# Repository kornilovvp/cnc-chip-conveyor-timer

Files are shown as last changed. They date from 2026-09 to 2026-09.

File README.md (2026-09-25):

# CNC Chip Conveyor Timer

Interval timer for a CNC chip conveyor. It presses the conveyor's **START** and
**STOP** buttons for you, in a loop, so the coolant on the swarf drains back
into the machine instead of leaving with the chips.






<!-- photo of the box on the machine: docs/photo.jpg -->

## Why

On many machines the chip conveyor is either always on or run by hand. Run
continuously it pulls the swarf out of the coolant too fast: the chips land in
the bin still wet, and a surprising amount of coolant goes with them.

Run the conveyor in short bursts instead, with a pause in between, and the
coolant drains off the belt while it stands still. Chips come out drier, the
coolant stays where it belongs.

This box does the pressing. One illuminated button, three run / pause programs,
one relay for START and one for STOP.

## How it works

```mermaid
stateDiagram-v2
    direction LR
    [*] --> SETTLE : 1 click, switched on
    SETTLE --> START_PULSE : 100 ms, both relays off
    START_PULSE --> RUN : START held 500 ms
    RUN --> STOP_PULSE : T1 elapsed
    STOP_PULSE --> PAUSE : STOP held 500 ms
    PAUSE --> START_PULSE : T2 elapsed
    [*] --> SETTLE_STOP : 2..4 clicks, mode selected
    SETTLE_STOP --> STOP_PULSE : 100 ms, both relays off
    RUN --> LAST_STOP : switched off
    PAUSE --> LAST_STOP : switched off
    LAST_STOP --> [*] : 100 ms both off, then STOP held 500 ms
```

| Mode | T1 — conveyor runs | T2 — conveyor rests |
|:---:|:---:|:---:|
| 1 | 90 s | 360 s (6 min) |
| 2 | 90 s | 720 s (12 min) |
| 3 | 90 s | 1080 s (18 min) |

The two buttons are never pressed at the same time. The rule is enforced in
the relay driver itself — pressing one lets go of the other first — and every
start of the cycle begins with 100 ms of neither button pressed.

Switching off is not a plain release of the relays. The machine holds itself
running once START has been pressed, so a timer that simply let go mid-run
would leave the conveyor going. Instead, from whatever phase the cycle is in,
the timer releases both relays for 100 ms, presses STOP once more for 500 ms,
and only then rests. A pause is no exception: STOP on a conveyor that already
stands still does nothing.

Both relays rest with their coils off, so the operator's panel buttons work as
if the timer were not there. To press a button the timer energises a relay for
500 ms: START through a normally-open contact across the START button, STOP
through a normally-closed contact in series with the machine's STOP circuit.

After **4 hours** of continuous running the timer presses STOP, switches
itself off and sounds a 15 s alarm.

## Operating it

Everything is done with the one button. A command is a series of quick clicks;
the series ends when the button stays released for 0.7 s.

| Clicks | Action |
|:---:|---|
| 1 | Switch on in the stored mode / switch off (the conveyor is stopped) |
| 2 | Mode 1 |
| 3 | Mode 2 |
| 4 | Mode 3 |

Selecting a mode stores it in flash and takes it up at once, from OFF as well
as on the run: STOP is pressed, the conveyor rests for the mode's T2, and the
cycle goes on from there with START. One click switches on with START straight
away. More than four clicks count as four. The stored mode survives a power
cycle; the device always powers up switched off.

**Sounds**

| Event | Buzzer |
|---|---|
| Power on | 2 s |
| Cycle started or restarted | 2 s |
| Switched off by the operator | 0.5 s |
| 4 h auto-off | 15 s |
| First power-on (blank settings) | SOS, once |
| Settings flash unusable | SOS at every power-on |

**Button lamp**

| State | Lamp |
|---|---|
| Off | dark |
| Running | *N* blinks, 3 s dark, *N* blinks… where *N* is the mode |
| Settings flash unusable, switched off | fast flicker |

**On-board LED (HL1)** mirrors the state for whoever has the lid open: lit
during start-up, a flash every 3 s when off, and a distinct pattern for each
phase of the cycle while running.

### When the settings flash fails

The mode is kept in a flash page that is rewritten only when the mode changes.
A power loss in the middle of a write leaves a damaged record; on the next
power-on the page is repaired automatically and the last good mode is kept. If
even that fails the timer keeps working with the mode held in RAM, and says so:
SOS instead of the power-on beep, and the button lamp flickers whenever the
device is off. It can still be switched on and off and used normally until the
board is repaired.

## Hardware

Board `PCB1_main_rev1`, 24 V supply.

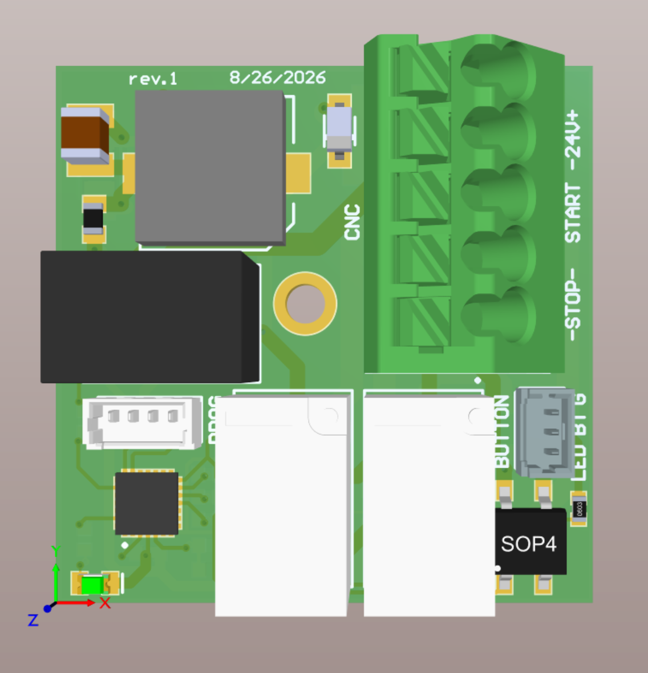
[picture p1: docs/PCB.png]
PCB1_main_rev1, 3D view of the top side


*Top side, Altium 3D view. The terminal block at the top right goes to the
machine: 24 V supply, START and STOP. The two white relays press START and
STOP. PROG is the SWD connector X2; the connector marked BUTTON goes to the
illuminated button.*

| MCU pin | Signal | Circuit |
|---|---|---|
| PB0 | `BUTTON_IN` | 10 kΩ pull-up, button to GND through 1 kΩ — active low |
| PA6 | `BUTTON_LED_ON` | 1 kΩ → CPC1014N solid-state relay → 24 V → button lamp |
| PA5 | `START_RELAY` | 1 kΩ → CPC1014N → relay K1, NO contact across the machine's START button. Energised to press |
| PA7 | `STOP_RELAY` | 1 kΩ → CPC1014N → relay K2, NC contact in series with the machine's STOP circuit. Energised to press |
| PB3 | `BUZZER` | 1 kΩ → CPC1014N → MLT-9650 active buzzer |
| PB7 | `DEBUG_LED` | 1 kΩ → HL1 |

### Rev 1 errata

- The START and STOP relay outputs were swapped on the connector in the
  original rev 1 netlist. Fixed on 2026-09-09 by renaming the nets in the
  schematic; the firmware pin labels follow (PA5 = START, PA7 = STOP). Boards
  built from the earlier netlist need the firmware labels swapped back.
- The 1 kΩ resistors feeding the CPC1014N inputs give ≈ 2.1 mA against a
  guaranteed turn-on of 2 mA. Works, but marginal; 330–470 Ω next revision.
- HL1 gets ≈ 1.2 mA and is dim.

Design sources (Altium) are in [`hardware/`](hardware/). Ready to
use: [schematic](docs/CNC_rev1_2026-09-09.PDF) and
[assembly drawing](docs/Assembly.PDF) in `docs/`.

## Firmware

STM32CubeMX generates the HAL project (`firmware/CNC_TIMER.ioc`); IAR
Embedded Workbench builds it (`firmware/EWARM/Project.eww`). Everything the device does lives in
the `Core/` sources; the CubeMX-generated files are only touched inside their
`USER CODE` sections.

A prebuilt image is kept in [`firmware/hex/`](firmware/hex/) — flash it over
SWD with STM32CubeProgrammer at `0x08000000` if you only want to run the board.

### Building

1. IAR Embedded Workbench for Arm 9.1 (any 9.x should do). STM32CubeMX is only
   needed if you change `CNC_TIMER.ioc`; the generated files are committed.
2. Open `firmware/EWARM/Project.eww`, build. The image lands in
   `firmware/EWARM/CNC_TIMER/Exe/CNC_TIMER.hex` (the output converter is on).
3. Flash over SWD. X2 has no NRST line, so the debugger cannot reset the
   board — power-cycle it instead.
4. Compiler optimisation is **switched off** (Level: None) in the project
   file, and the shipped `.hex` is built that way. Regenerating the project
   in CubeMX puts back its default, High / Size — set it to None again under
   Project → Options → C/C++ Compiler → Optimizations.

| Module | Job |
|---|---|
| `button.c` | Debounce, click-series detector, deaf/listening gate |
| `relay.c` | The two relays, mutual exclusion, polarity |
| `cycle.c` | START / RUN / STOP / PAUSE state machine |
| `settings.c` | Mode in the last flash page, append-only log, repair, fault flag |
| `indicator.c` | Button lamp: blink bursts, flicker |
| `buzzer.c` | Beeps and the Morse SOS |
| `debug_led.c` | HL1 patterns |
| `app.c` | Power-on signature, OFF / RUN, click dispatch, 4 h clock, sounds |
| `main.c` | Wiring only |

The main loop never blocks. `Button_Tick()` runs from SysTick every 1 ms; every
other module is polled from the loop and works from `HAL_GetTick()`.

The settings page is the last 2 KB of flash (`0x0801F800`); the linker script
ends ROM one page early so no code can land there. Firmware from before
2026-09-24 had five programs; its stored mode is not carried over — the first
power-on after the update repairs the page and starts at mode 1.

Every module exposes a `volatile` `g_*` structure for the IAR Live Watch
window — counters, live values, measured timings — so the board can be read
without a printf.

## Repository layout

```
firmware/   STM32CubeMX project (CNC_TIMER.ioc), HAL drivers, IAR workspace in EWARM/
hardware/   Altium Designer sources of PCB1_main_rev1 (schematic, PCB, Draftsman assembly drawing)
docs/       schematic and assembly PDFs, PCB render, operator's guide (A4), button labels (150 x 20 and 50 x 150 mm)
```

For the operator: [one-page guide](docs/operator-guide-A4.pdf) and a
label to stick next to the button, [150 × 20 mm strip](docs/button-label-150x20.pdf)
or [50 × 150 mm vertical](docs/button-label-50x150.pdf) — all generated from the
`.html` files beside them; print at 100 %.

## Status

Testing. The firmware builds and runs on the rev 1 board: button, relay
cycle, mode selection and storage, indication and sounds all work. Long-run
behaviour (the 4 h auto-off, flash wear, the fault paths) is still being
exercised before the first release.

## License

MIT — see [`LICENSE`](LICENSE).

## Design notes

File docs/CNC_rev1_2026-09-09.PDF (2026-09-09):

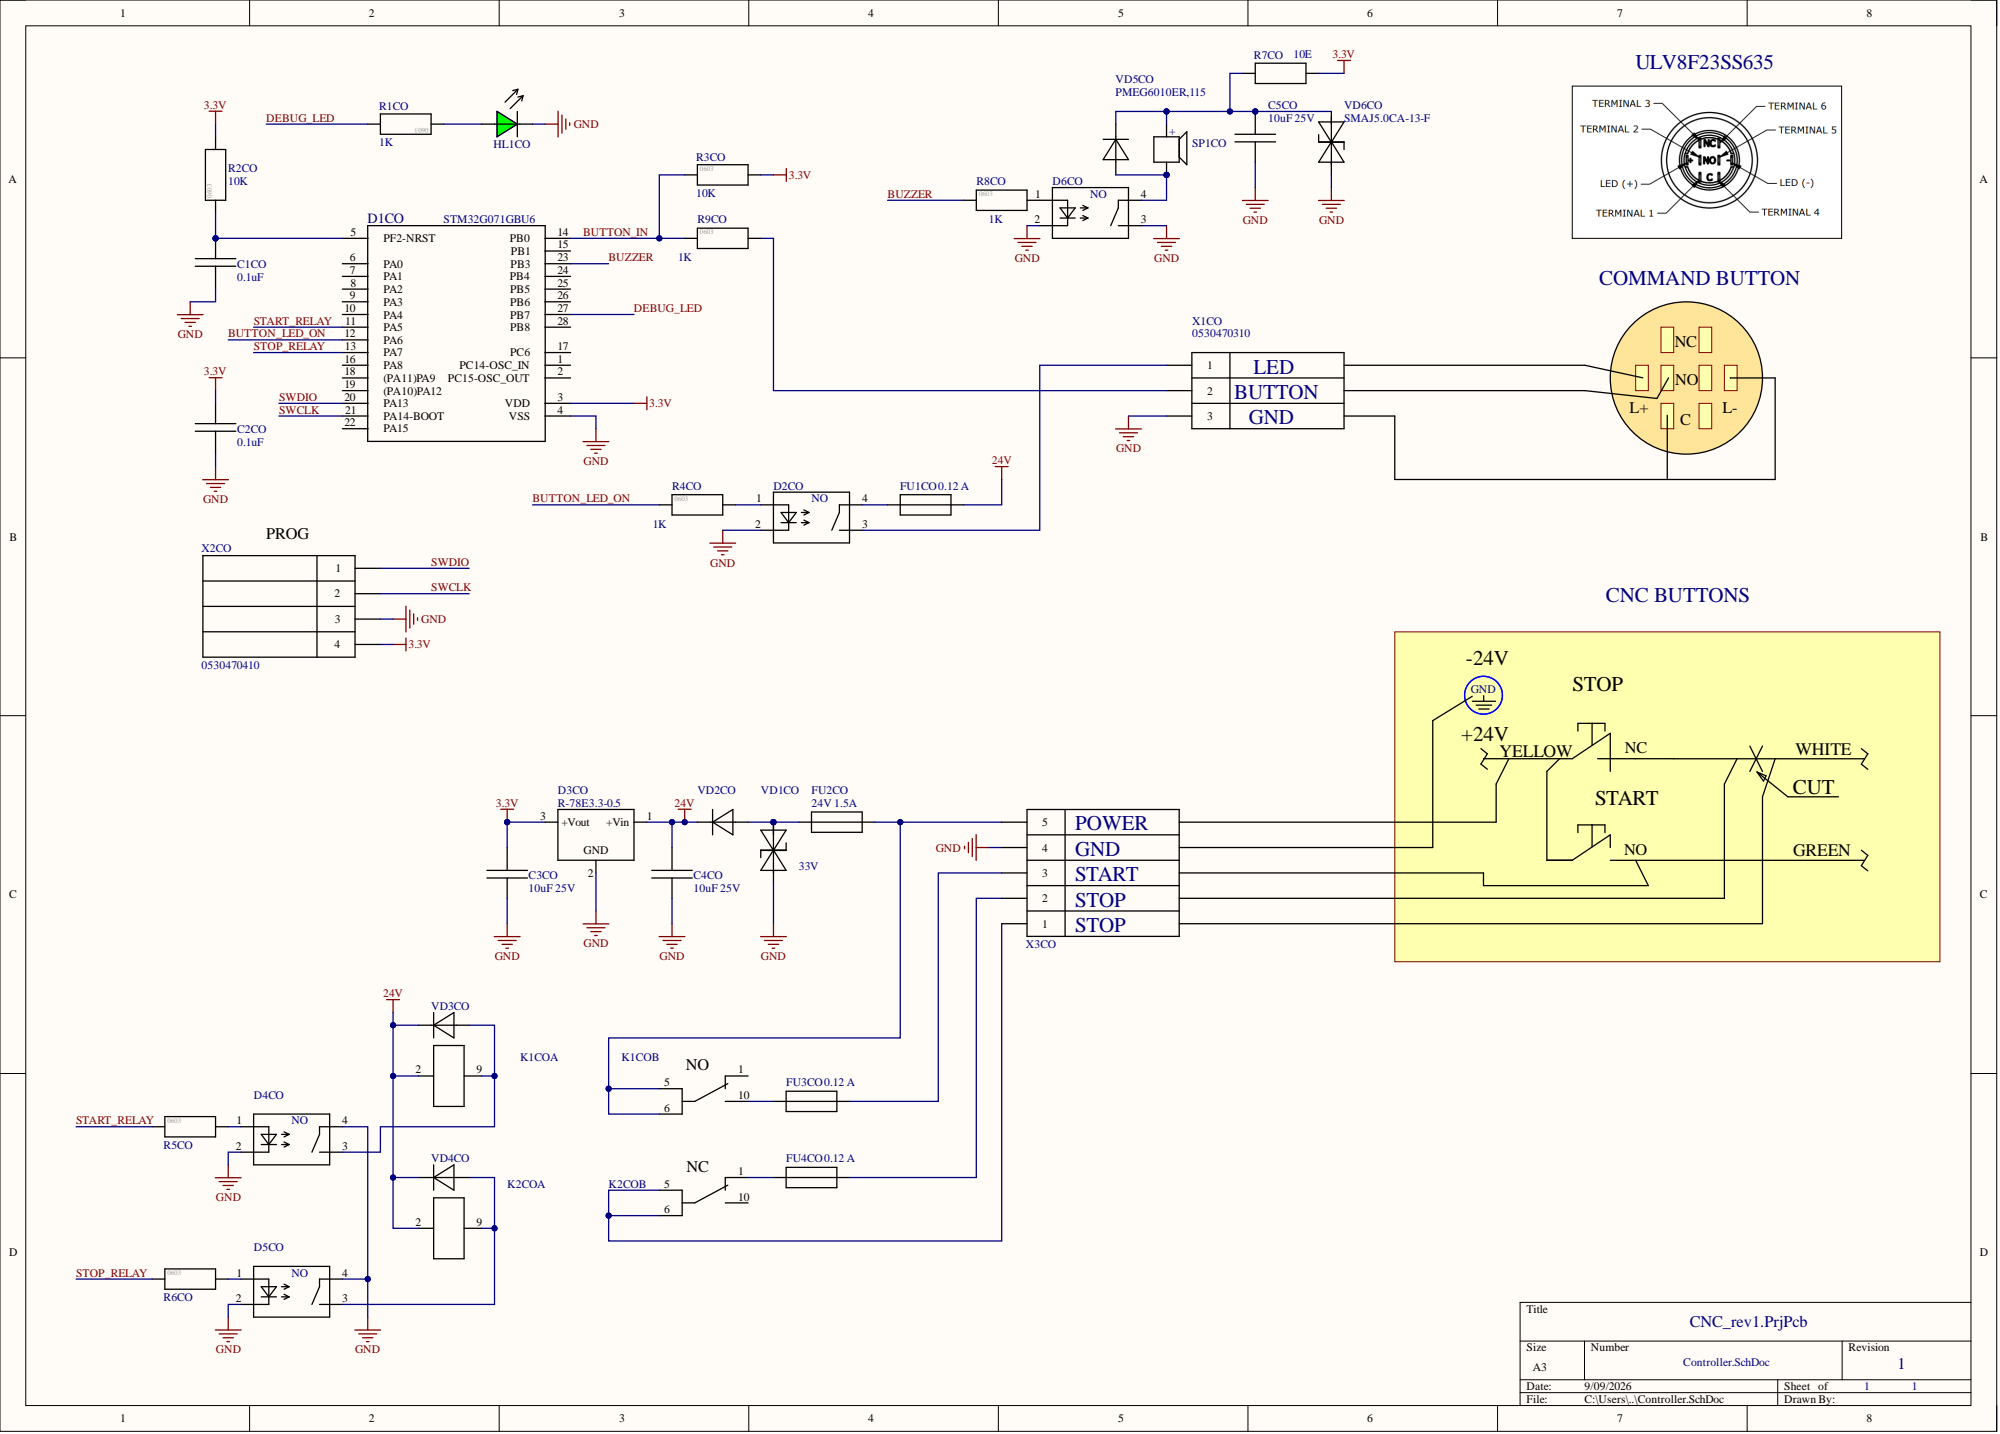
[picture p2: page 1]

4 | GND
3 | START
2 | STOP
1 | STOP

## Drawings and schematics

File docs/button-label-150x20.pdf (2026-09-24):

## ON / OFF

P1

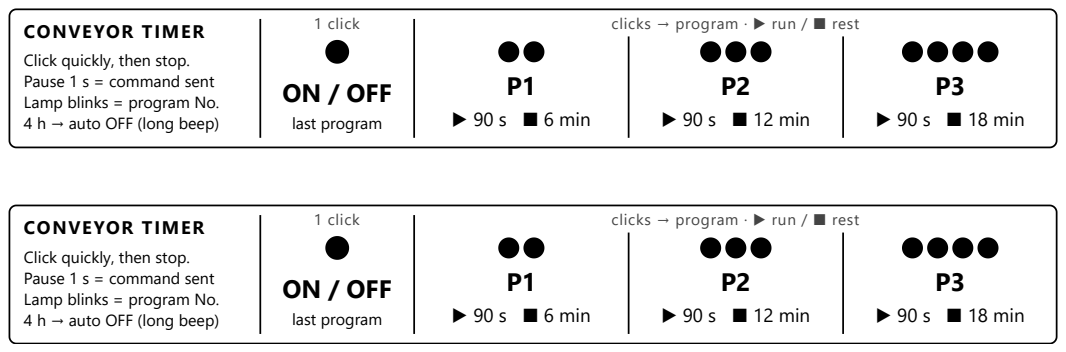
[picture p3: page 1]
1 click; last program; ▶ 90 s ■ 6 min; ▶ 90 s ■ 12 min; ▶ 90 s ■ 18 min; ON / OFF

CONVEYOR TIMER
Click quickly, then stop.
Pause 1 s = command sent
Lamp blinks = program No.
4 h → auto OFF (long beep)

clicks → program · ▶ run / ■ rest

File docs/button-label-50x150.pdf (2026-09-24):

## CONVEYOR TIMER

# ON / OFF

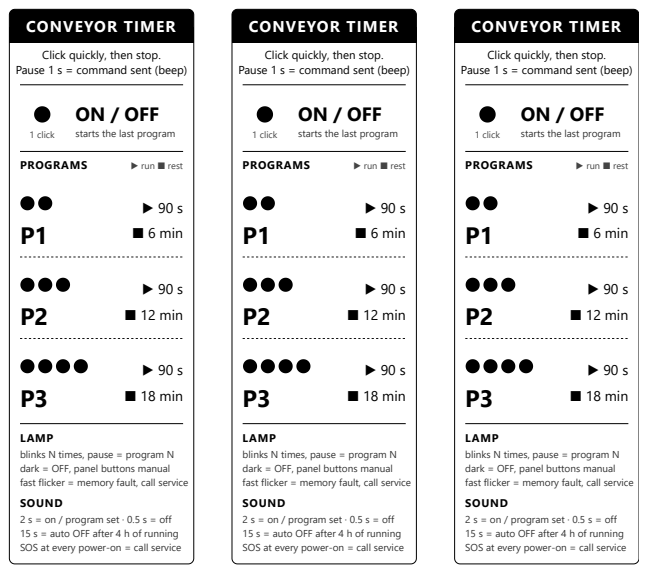
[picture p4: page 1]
1 click; PROGRAMS; ▶ run ■ rest; ▶ 90 s ■ 6 min; ▶ 90 s ■ 12 min; ▶ 90 s ■ 18 min; CONVEYOR TIMER

Click quickly, then stop.
Pause 1 s = command sent (beep)

ON / OFF

starts the last program

LAMP
blinks N times, pause = program N
dark = OFF, panel buttons manual
fast flicker = memory fault, call service
SOUND
2 s = on / program set · 0.5 s = off
15 s = auto OFF after 4 h of running
SOS at every power-on = call service

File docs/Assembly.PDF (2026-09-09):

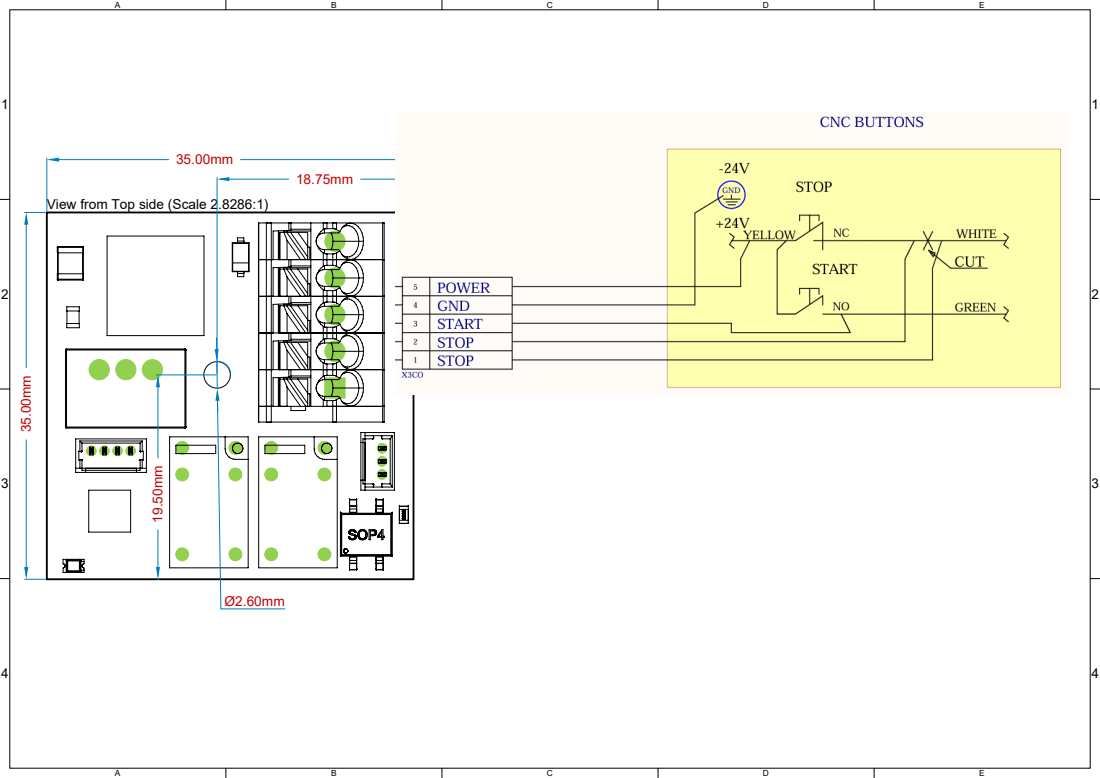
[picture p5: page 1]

View from Top side (Scale 2.8286:1)

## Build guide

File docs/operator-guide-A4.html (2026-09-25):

# CNC Chip Conveyor Timer

Operator's guide · one illuminated button, three programs · board PCB1 rev 1

What it does. The timer presses the conveyor's START and STOP buttons for you, in a loop: run for a while, stop for a while, repeat. While the conveyor stands still the coolant drains off the swarf back into the machine, so the chips reach the bin drier and the coolant stays where it belongs. When the timer is switched off, the START and STOP buttons on the panel work exactly as before.

## Controls — one button

A command is a series of quick clicks. Click, click, click… then stop. The command is accepted 0.7 s after the last click (a beep confirms it).

Clicks | Action
● | Switch ON in the last used program / switch OFF (the conveyor stops)
●● | Program 1
●●● | Program 2
●●●● | Program 3

Choosing a program takes effect at once, timer ON or OFF: the conveyor stops, rests for the program's pause, then the cycle runs. The choice is remembered after power-off. One click switches on with the conveyor starting straight away. The timer always powers up switched OFF.

## Programs

Program | Conveyor runs | Conveyor rests
1 | 90 s | 360 s (6 min)
2 | 90 s | 720 s (12 min)
3 | 90 s | 1080 s (18 min)

Each START and STOP press lasts 0.5 s. Longer rest = drier chips, slower removal. Start with program 1; if the chips still come out wet, go to 2 or 3.

Automatic switch-off. After 4 hours of continuous running the timer stops the conveyor, switches itself off and sounds a 15 s signal. One click starts it again.

## What you hear

Signal | Meaning
Beep, 2 s | Power on — ready after the beep
Beep, 2 s | Program started or changed
Short beep, 0.5 s | Switched off by the button
Long signal, 15 s | 4-hour automatic switch-off
Morse SOS ··· −−− ··· | Settings memory: first power-on (once, normal) — or a memory fault if it repeats at every power-on

## What you see — the button lamp

Lamp | Meaning
Dark | Timer OFF, panel buttons in manual use
Blinks N times, 3 s pause, repeat | Running program N
3 blinks at power-on | Self-test passed
Fast flicker while OFF | Settings memory fault — the timer still works, the program is kept only until power-off. Call service.

## Good to know

· Switching off always ends with a STOP press, so the conveyor stops even if it was running at that moment.

· The two relays can never press START and STOP at the same time; every start begins with both released.

· Clicks during the power-on beep are ignored — wait for the lamp to go dark, then click.

· Too many clicks? Anything over four counts as four (program 3).

· A green LED inside the box shows the state for the technician: lit at power-on, one flash every 3 s when OFF, a different rhythm in each phase when running.

Before opening the box switch the machine off. The relays carry the machine's START/STOP circuit; the board runs on 24 V.

cnc-chip-conveyor-timer · github.com/kornilovvp/cnc-chip-conveyor-timer Firmware 2026-09 · MIT

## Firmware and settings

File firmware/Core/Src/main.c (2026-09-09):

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
/* Includes ------------------------------------------------------------------*/
#include "main.h"

/* USER CODE BEGIN Includes */
#include "app.h"
#include "button.h"
#include "buzzer.h"
#include "cycle.h"
#include "debug_led.h"
#include "indicator.h"
#include "relay.h"
#include "settings.h"
/* USER CODE END Includes */

IWDG_HandleTypeDef hiwdg;

/* USER CODE BEGIN PV */
static volatile uint32_t g_loops;   /* main loop iterations, for Live Watch */

/* USER CODE END PV */

void SystemClock_Config(void);
static void MX_GPIO_Init(void);
static void MX_IWDG_Init(void);
/**
  * @brief  The application entry point.
  * @retval int
  */
int main(void)
{

  /* MCU Configuration--------------------------------------------------------*/

  /* Reset of all peripherals, Initializes the Flash interface and the Systick. */
  HAL_Init();

  /* Configure the system clock */
  SystemClock_Config();

  /* Initialize all configured peripherals */
  MX_GPIO_Init();
  MX_IWDG_Init();
  /* USER CODE BEGIN 2 */
  /* Relay_Init() already ran inside MX_GPIO_Init(): see MX_GPIO_Init_2. */
  Button_Init();
  Cycle_Init();
  Indicator_Init();
  Buzzer_Init();
  Settings_Init();
  App_Init();

  /* Start-up finished without an error: HL1 lights up and stays lit. */
  DebugLed_Init();
  /* USER CODE END 2 */

  /* Infinite loop */
  /* USER CODE BEGIN WHILE */
  while (1)
  {
    /* USER CODE END WHILE */

    /* USER CODE BEGIN 3 */
    /* The IWDG resets the MCU after ~32.7 s (LSI / 256, reload 4095). */
    HAL_IWDG_Refresh(&hiwdg);

    g_loops++;

    DebugLed_Task();
    Buzzer_Task();
    Indicator_Task();
    Cycle_Task();
    App_Task();
  }
  /* USER CODE END 3 */
}

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


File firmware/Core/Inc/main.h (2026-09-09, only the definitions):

#define START_RELAY_Pin GPIO_PIN_5
#define START_RELAY_GPIO_Port GPIOA
#define BUTTON_LED_ON_Pin GPIO_PIN_6
#define BUTTON_LED_ON_GPIO_Port GPIOA
#define STOP_RELAY_Pin GPIO_PIN_7
#define STOP_RELAY_GPIO_Port GPIOA
#define BUTTON_IN_Pin GPIO_PIN_0
#define BUTTON_IN_GPIO_Port GPIOB
#define BUZZER_Pin GPIO_PIN_3
#define BUZZER_GPIO_Port GPIOB
#define DEBUG_LED_Pin GPIO_PIN_7
#define DEBUG_LED_GPIO_Port GPIOB

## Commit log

2026-09-09 Initial import: CNC chip conveyor timer
    Firmware for STM32G071 (CubeMX + IAR): one-button click-series control,
    START/STOP relay cycle with five run/pause programs, mode stored in the
    last flash page with repair and fault handling, lamp / buzzer / HL1
    indication, 4 h auto-off. Written, not yet built on hardware.
    Hardware: Altium sources of PCB1_main_rev1, schematic PDF and gerbers in
    docs/.
    [CNC_rev1.PrjPcb, Controller.SchDoc, PCB.PcbDoc]
2026-09-09 Status: builds and runs on the rev 1 board, under test
    README status badge and section updated. Long-run scenarios (4 h auto-off,
    flash wear, fault paths) still to be exercised before the first release.
2026-09-09 CubeMX: copy only the necessary library files
    Regenerated with ProjectManager.LibraryCopy=1: the unused HAL and LL
    drivers are gone (100+ files), the fourteen that are compiled remain.
    Linker script, user code sections and the IAR file list are unchanged.
2026-09-09 Add prebuilt firmware image
    firmware/hex/cnc-chip-conveyor-timer.hex, built from this tree with IAR
    EWARM 9.1; flash over SWD at 0x08000000.
2026-09-09 Relays: document the hold-at-rest logic correctly
    Both relays are energised while the timer is idle; pressing a button
    means releasing its relay for the pulse. Earlier comments described this
    as a board polarity error -- it is the contact wiring by design. Code is
    unchanged; relay.h, main.c, README and the checklist now say so.
    [main.c, relay.h]
2026-09-09 README: explain why the relay contacts are wired inverted
2026-09-09 App: read the tick afresh for the 4 h clock
    now was captured at the top of App_Task() and s_run_t0 set later inside
    App_Start(); when the tick moved in between (certain during a flash page
    erase on a mode change) the subtraction wrapped and the auto-off alarm
    fired at once: 15 s beep, relays released. Use HAL_GetTick() directly.
2026-09-09 docs: operator's guide (A4) and button label (150x20 mm)
    HTML sources with print-exact @page sizes, plus the rendered PDFs.
2026-09-09 docs: vertical 50x150 mm button label
2026-09-09 hardware: add Draftsman assembly drawing
2026-09-09 Assembly.PDF added
2026-09-09 Relays: START/STOP swap fixed in the netlist, polarity back to active high
    The rev 1 netlist had the START and STOP relay outputs swapped on the
    connector. The schematic nets are renamed (hardware/), and the firmware
    follows: PA5 = START_RELAY, PA7 = STOP_RELAY in CNC_TIMER.ioc and main.h.
    With the contacts now understood -- START normally open across the START
    button, STOP normally closed in series with the STOP circuit -- both
    relays rest with their coils off and are energised to press, so
    RELAY_*_ACTIVE_LOW are 0 again. Comments and README updated; the
    "inverted contacts" section is gone.
    [Controller.SchDoc, PCB.PcbDoc]
2026-09-09 Mode timings: 15/15, 30/60, 45/90, 60/120, 60/240 s
    Longer rests than the first guess (5/5 ... 30/60). Table in app.c; README,
    operator's guide and both button labels regenerated to match.
    [PCB.PcbDoc]
2026-09-09 Hardware: updated schematic project and assembly drawing; refresh prebuilt image
    docs/Assembly.PDF regenerated from the corrected schematic. The .hex is
    rebuilt with PA5 = START / PA7 = STOP, active-high relays and the new
    mode timings.
    [CNC_rev1.PrjPcb]
2026-09-09 Updated schematic and fmw delays
2026-09-24 Three programs: 90/360, 90/720, 90/1080 s
    Five run / rest programs become three, all with 90 s of conveyor run and
    6, 12 or 18 min of rest. 2..4 clicks select them; longer series saturate
    at four, program 3.
    The settings record magic changes (0x5E77 -> 0x5E73), so a mode stored by
    the five-program firmware is not carried over: the first power-on after
    the update repairs the page and starts at program 1, with the normal beep.
    README, operator's guide and both button labels regenerated, times given
    in seconds with minutes alongside. README also: dead links to the old
    schematic PDF and gerber archive replaced, build step 4 corrected (the
    project already builds with optimisation None). Prebuil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
    [app.c, settings.c]

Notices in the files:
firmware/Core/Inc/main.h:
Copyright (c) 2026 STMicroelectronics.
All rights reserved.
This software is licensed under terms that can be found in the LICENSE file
